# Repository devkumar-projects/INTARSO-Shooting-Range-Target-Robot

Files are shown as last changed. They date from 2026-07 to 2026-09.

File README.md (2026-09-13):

# INTARSO — Shooting-Range Target Robot Controller







A full electronics and control-system retrofit for **INTARSO**, a motorized target-retrieval robot used on a shooting range: the robot rides on a rail, carries a paper target out to a commanded distance (up to 24 m), presents it front/side/back on command, detects when it's been hit, and reports live telemetry to a wireless tablet interface — all built around an **ESP32**, a **VESC** motor controller, and a 2D **LiDAR** rangefinder.

This project was delivered by **AMJE Arts et Métiers Junior Études** in partnership with **JEECE** (a fellow Junior-Entreprise specialized in embedded electronics), to replace the robot's original, failing control electronics end-to-end.

<p align="center">
  <a href="https://youtube.com/shorts/YrYRk8fM58c">
    INTARSO on-site demonstration — watch on YouTube
  </a>
  <br>
  <em>▶️ <a href="https://youtube.com/shorts/YrYRk8fM58c">Watch the on-site demonstration on YouTube</a></em>
</p>

<p align="center">
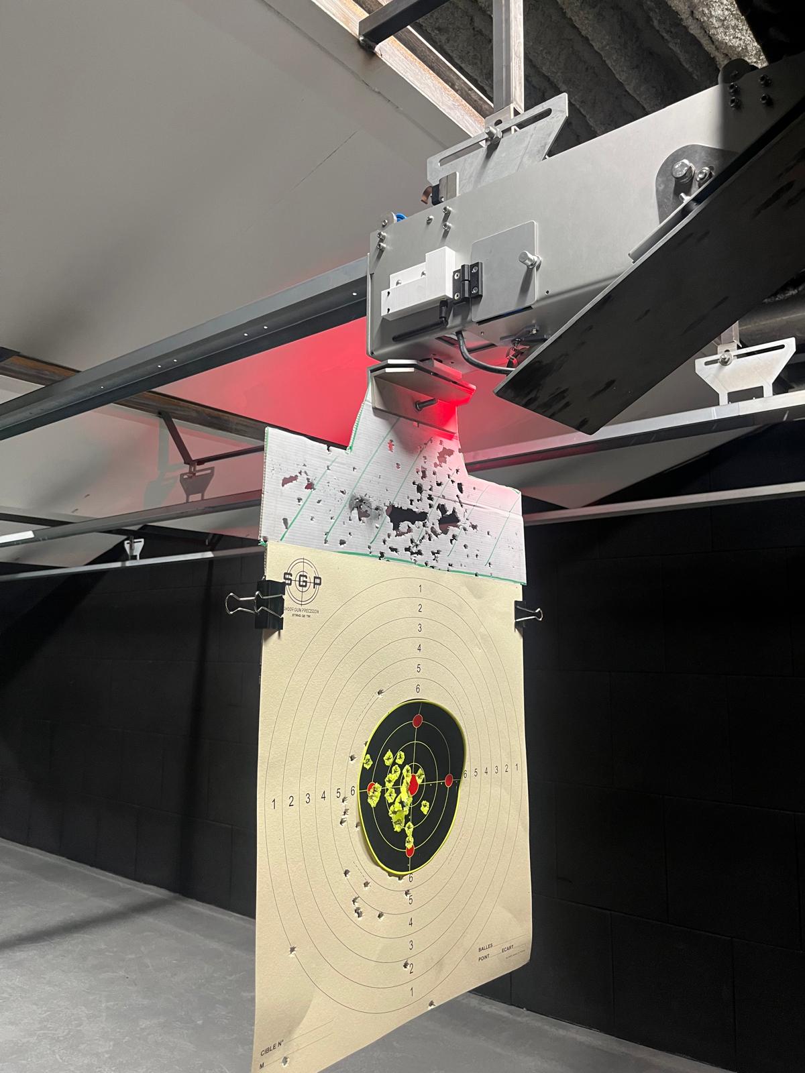
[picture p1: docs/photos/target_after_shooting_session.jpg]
INTARSO target after a live shooting session
  
  &nbsp;
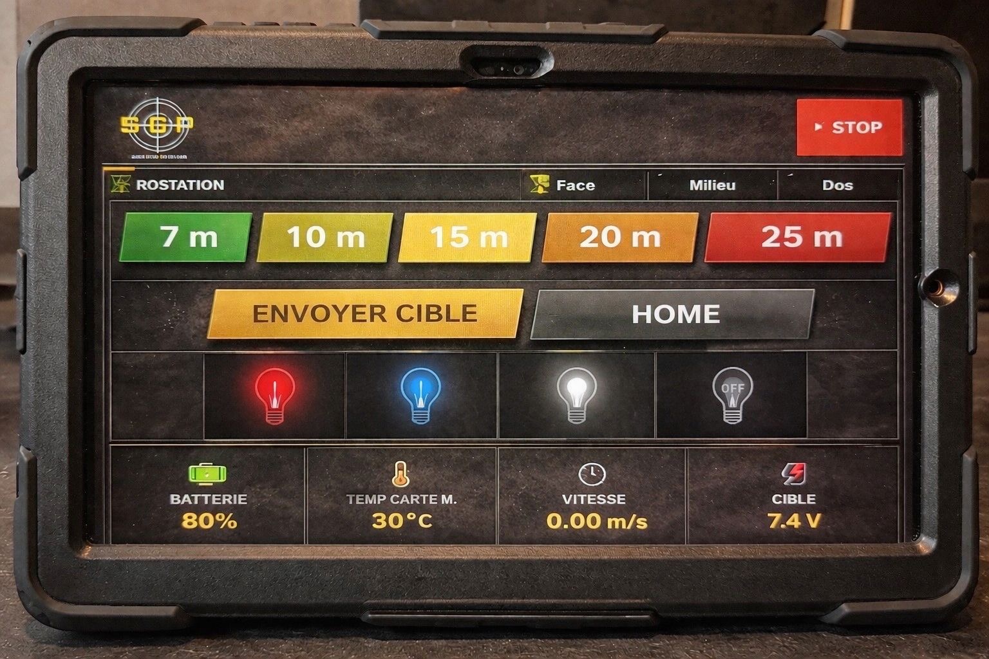
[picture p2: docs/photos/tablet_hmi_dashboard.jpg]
Wireless tablet HMI dashboard
  
</p>
<p align="center"><em>Left: the target board after a live session — the position-control loop reliably parked the robot at the commanded distances. Right: the wireless tablet dashboard (distance presets, live telemetry, target orientation, spot lighting).</em></p>

## Project outcome

The retrofit is **fully operational**: the robot accepts a target distance from the tablet (preset buttons or manual fine adjustment), drives there under closed-loop LiDAR feedback, holds position accurately enough for competitive shooting, detects impacts on the target via unexpected wheel motion while parked, and automatically returns home after an authenticated operator confirms the safety prompt. Every safety interlock described below (LiDAR signal loss, overcurrent/overheat, mechanical stall) was implemented and is active in the deployed firmware.

## System architecture

```mermaid
graph LR
    Tablet["Tablet / phone<br/>(any browser)"] <-->|WiFi AP<br/>HTTP + WebSocket| ESP32["ESP32<br/>main controller"]
    ESP32 <-->|UART 115200<br/>VescUart| VESC["VESC<br/>FOC motor controller"]
    ESP32 <-->|UART 921600| LiDAR["2D LiDAR<br/>rangefinder"]
    ESP32 -->|PWM| Servo["Servo motor<br/>target orientation"]
    ESP32 -->|P9813 protocol| LED["RGB spot LED<br/>status / hit indicator"]
    VESC -->|3-phase| Hub["Hub motor<br/>139 mm wheel"]
```

| Signal | ESP32 pin | Peripheral pin |
|---|---|---|
| VESC UART | GPIO 16 (RX) / 17 (TX) | TX / RX |
| VESC 5V | — | powers the LiDAR's 5V rail (shared, for a stable supply) |
| LiDAR UART | GPIO 14 (RX) / 27 (TX) | TX / RX |
| Servo PWM | GPIO 5 | signal (brown = GND, red = 5V) |
| P9813 LED driver | GPIO 19 (clock) / 23 (data) | CIN / DIN |

**Motor**: hub motor, 139 mm wheel, configured in the VESC as a large outrunner (2000 g profile), 20 poles (10 pole pairs), sensorless FOC, 150 W max power loss, driven directly (no gearbox — the wheel *is* the motor rotor).

## Control theory: position servo as state feedback with integral action

The firmware implements the position loop as a discrete PID on the LiDAR distance error. That PID is not an arbitrary heuristic — it's the direct discretization of a **state-feedback controller with integral action**, the same design pattern used in this author's other control-theory projects ([`RST-controller-for-an-inverted-pendulum`](https://github.com/devkumar-projects/RST-controller-for-an-inverted-pendulum), [`Control-of-an-instable-system-using-digital-state-feedback`](https://github.com/devkumar-projects/Control-of-an-instable-system-using-digital-state-feedback)). The derivation below documents the theoretical basis for the structure that was empirically tuned on the physical system.

**Plant model.** Treating the hub-motor-driven cart as a first-order velocity system (duty cycle → acceleration, with viscous/back-EMF damping):

<p align="center">
  <picture>
    <source media="(prefers-color-scheme: dark)" srcset="docs/equations/eq1_plant_dark.png">
    equation
  </picture>
</p>

where `x₁` is position (measured by the LiDAR), `x₂` is velocity, `u ∈ [−1, 1]` is the commanded duty cycle, `a` is the effective damping coefficient, and `b` is the motor gain.

**Integral augmentation.** To reject steady-state error (static friction, cable drag, slope of the rail), the tracking error is integrated as an extra state:

<p align="center">
  <picture>
    <source media="(prefers-color-scheme: dark)" srcset="docs/equations/eq2_integral_dark.png">
    equation
  </picture>
</p>

**Augmented state-space system**, `X = [x₁, x₂, x₃]ᵀ`:

<p align="center">
  <picture>
    <source media="(prefers-color-scheme: dark)" srcset="docs/equations/eq3_statespace_dark.png">
    equation
  </picture>
</p>

**Full-state feedback control law**:

<p align="center">
  <picture>
    <source media="(prefers-color-scheme: dark)" srcset="docs/equations/eq4_control_law_dark.png">
    equation
  </picture>
</p>

which is exactly a PID acting on the position error, with the derivative term taken on measured velocity (avoiding derivative kick on setpoint changes) rather than on the error itself. Substituting the control law back into the state equation gives the closed-loop system matrix `A_cl = A − BK`; the theoretical design method is to place the three closed-loop poles of `det(sI − A_cl) = 0` (e.g. via pole placement or an LQR cost) to hit a target settling time and damping ratio, which is what would determine `K_p`, `K_i`, `K_d` from `a` and `b` in a fully model-based design.

**What the firmware actually does** is the discrete-time version of this law, tuned empirically directly on the robot (since identifying `a` and `b` precisely for a friction-varying rail is impractical):

```cpp
float P = Kp * erreur;
integral = constrain(integral + erreur * dt, -1000, 1000);   // anti-windup clamp
float I = Ki * integral;
float D = Kd * (erreur - erreur_precedente);                  // discrete derivative
float target_duty = constrain(P + I + D, -dynamic_max_duty, dynamic_max_duty);
```

with a 20 ms control period (50 Hz), an **anti-windup clamp** on the integral term, a **slew-rate limiter** on the output duty cycle (`ACCEL_STEP`) to avoid current spikes through the VESC, and a **dynamically reduced maximum duty cycle** below 300 mm from the target for a soft, precise final approach.

**Wheel kinematics** — converting motor electrical RPM to linear speed and distance:

<p align="center">
  <picture>
    <source media="(prefers-color-scheme: dark)" srcset="docs/equations/eq5_wheel_rev_dark.png">
    equation
  </picture>
</p>

<p align="center">
  <picture>
    <source media="(prefers-color-scheme: dark)" srcset="docs/equations/eq6_speed_dark.png">
    equation
  </picture>
</p>

where `p = 10` is the number of pole pairs (20 poles), so mechanical RPM `= ERPM/p`.

## Firmware behavior (main control loop)

1. **Network + sensor processing** — handles incoming HTTP/WebSocket requests, then reads and low-pass filters (0.6/0.4 coefficient) the LiDAR frame.
2. **LiDAR signal-loss safety** — if no valid LiDAR frame arrives for 500 ms while moving, the robot brakes immediately and the spot LED turns red.
3. **Telemetry broadcast** — every 500 ms, battery voltage, motor current, MOSFET temperature, and speed are read from the VESC and pushed to every connected client as JSON over WebSocket.
4. **Movement branch** (state-feedback/PID, above) — runs at 50 Hz while a target distance is active; stops and actively brakes (5 A brake current) once the error is under 120 mm and duty is under 5%. Overcurrent (>20 A) or overheat (>75°C) triggers an immediate stop.
5. **Hit-detection branch** — while parked, the firmware polls the VESC's RPM every 20 ms; unexpected wheel rotation (>0.20 RPM), occurring at least 5 seconds after the last move and only when the robot isn't already home, is interpreted as an impact. It lights the LED red, raises a `hittarget` flag broadcast to the tablet (triggering a full-screen alert requiring an authenticated operator confirmation), and automatically drives the robot home once acknowledged.
6. **Stall safety** — if the measured distance hasn't moved by more than 10 mm in 2 seconds despite an active duty command above 10%, the robot is considered mechanically stuck and stops.

## Wireless HMI

The ESP32 serves a self-contained single-page web app (no external hosting needed) over its own WiFi access point, with live state pushed over WebSocket:

- distance presets (7/10/15/20/24 m) plus manual ±1 m fine adjustment
- target orientation control (front / middle / back) via the servo
- spot-light color control (blue / white / off / red-on-hit)
- live telemetry: voltage, battery %, MOSFET temperature, speed, measured position
- a full-screen hit alert that requires an authenticated operator confirmation before the robot resumes normal operation

## Security and provisioning

The firmware does not contain a production Wi-Fi password or operator code. Before compiling:

1. Copy `firmware/main_controller/secrets.example.h` to `firmware/main_controller/secrets.h`.
2. Set a unique Wi-Fi password (at least 8 characters) and a random API token (at least 32 characters).
3. Keep `secrets.h` local; it is ignored by Git and must never be committed.

All actuator endpoints require the API token through the `X-API-Key` header. The browser dashboard asks for the token locally and stores it only in that browser's local storage. The OTA update endpoint is intentionally disabled; update the ESP32 through a controlled, authenticated flashing workflow.

## Mechanical design

Custom enclosure and mounts designed for this retrofit, 3D-printed and integrated onto the existing rail chassis:

<p align="center">
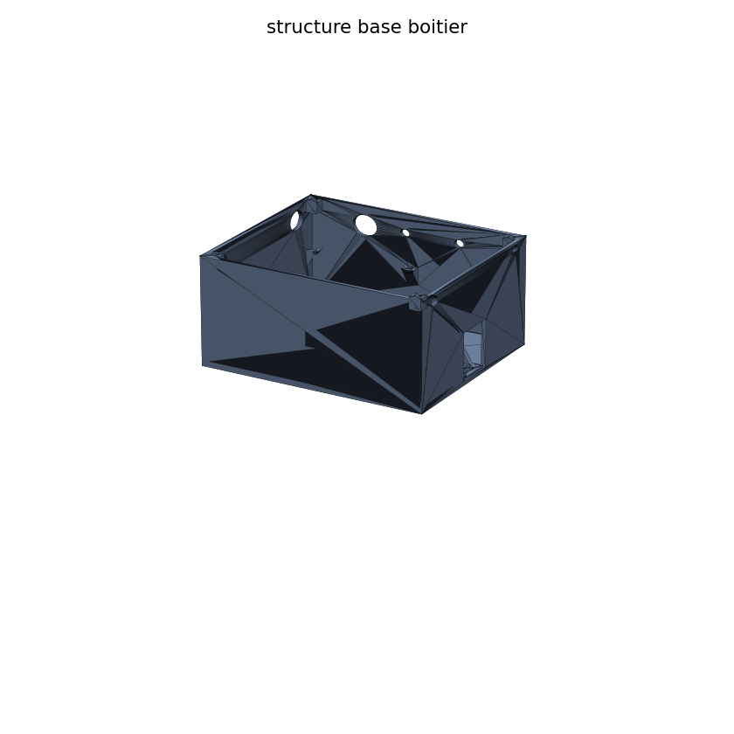
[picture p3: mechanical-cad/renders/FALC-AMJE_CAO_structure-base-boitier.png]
Enclosure base structure
  
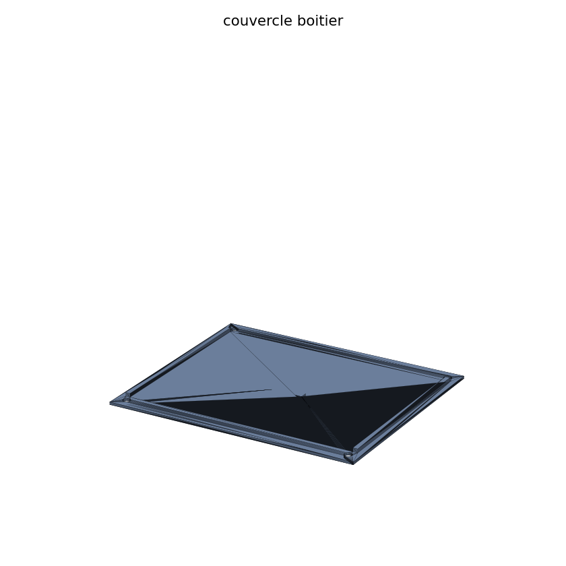
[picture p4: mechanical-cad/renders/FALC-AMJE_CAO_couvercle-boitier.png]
Enclosure lid
  
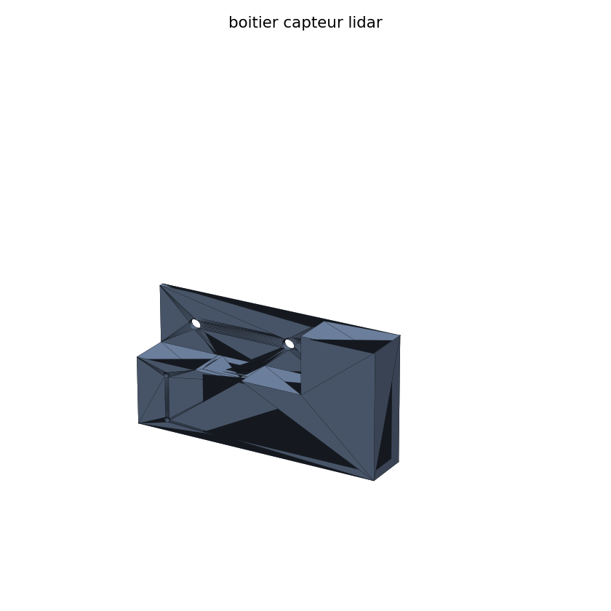
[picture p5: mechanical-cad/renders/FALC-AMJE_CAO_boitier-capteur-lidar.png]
LiDAR sensor housing
  
</p>
<p align="center">
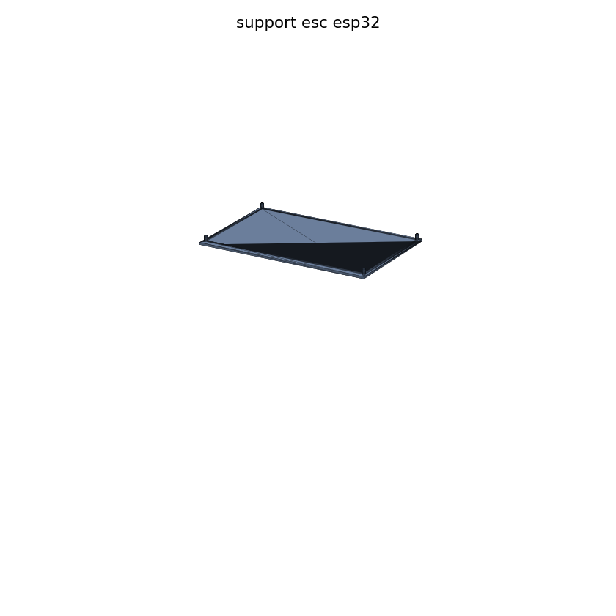
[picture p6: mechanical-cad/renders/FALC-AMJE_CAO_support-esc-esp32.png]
ESC/ESP32 mount
  
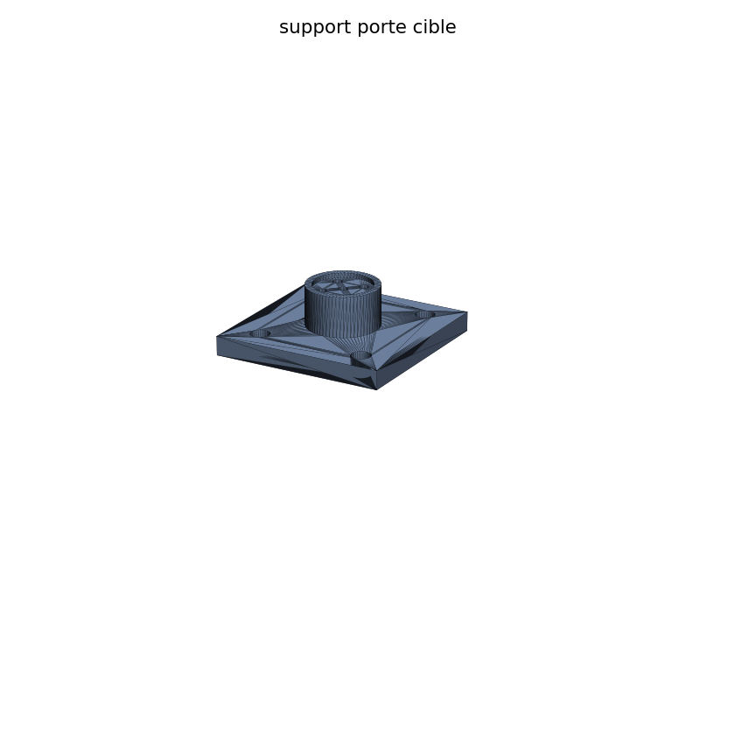
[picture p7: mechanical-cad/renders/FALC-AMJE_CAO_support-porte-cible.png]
Target-holder mount
  
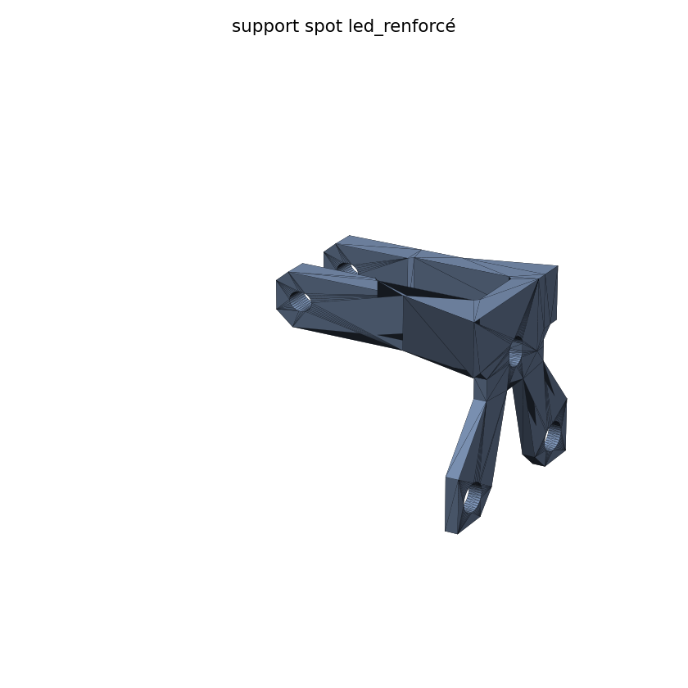
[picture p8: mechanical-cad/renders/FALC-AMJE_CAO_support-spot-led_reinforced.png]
Reinforced spotlight mount
  
</p>
<p align="center"><em>Renders generated directly from the STL files in this repository (matplotlib, shaded by face normals) — not marketing images.</em></p>

<p align="center">
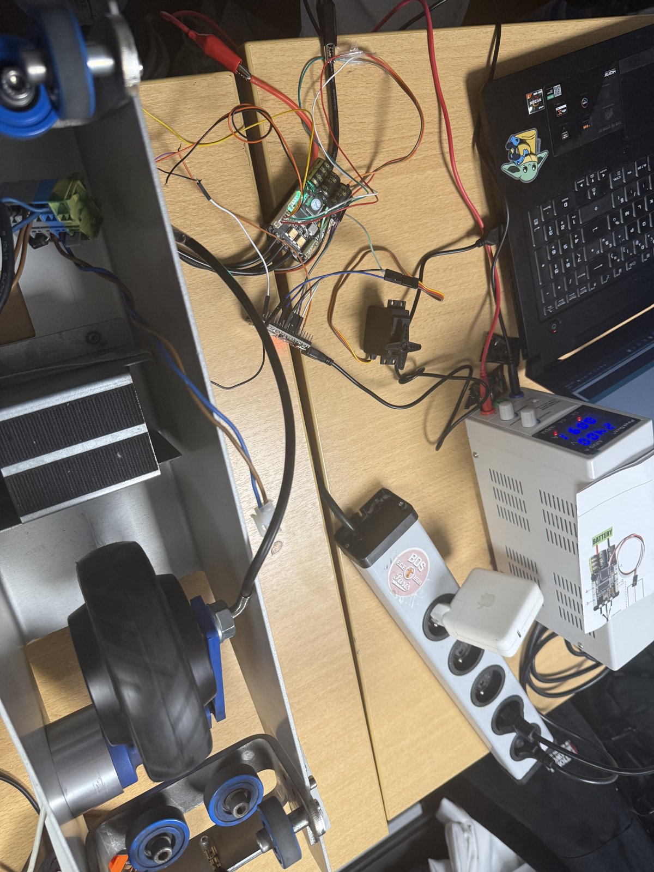
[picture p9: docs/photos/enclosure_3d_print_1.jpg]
3D-printed enclosure, printed part
  
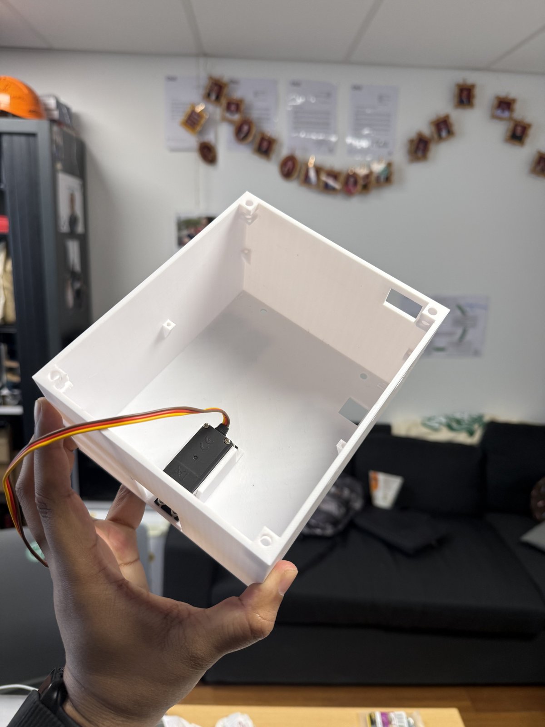
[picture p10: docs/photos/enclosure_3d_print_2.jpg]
3D-printed enclosure, second view
  
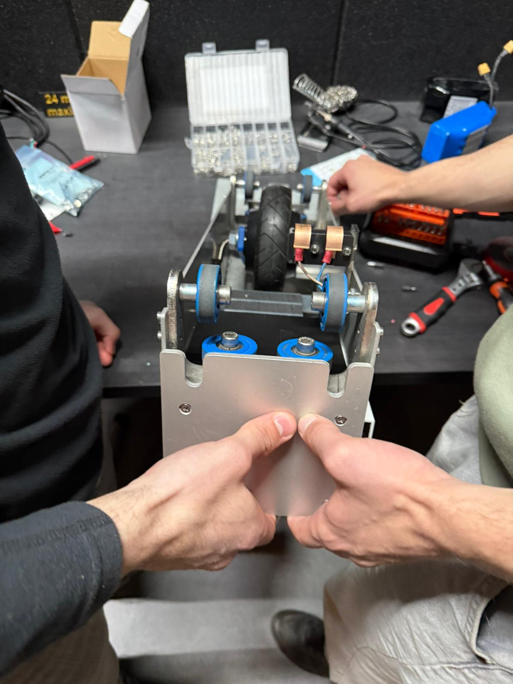
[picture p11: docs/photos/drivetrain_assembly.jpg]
Drivetrain and hub motor assembly
  
</p>
<p align="center"><em>The 3D-printed parts as manufactured, and the hub-motor drivetrain being assembled onto the rail carriage.</em></p>

Six parts were designed (STEP + STL provided in [`mechanical-cad/`](mechanical-cad)): the enclosure's base structure and lid, a dedicated LiDAR sensor housing, a mount for the ESC and ESP32, a mount for the target holder, and a reinforced mount for the spotlight (this last one needed reinforcing after the original print proved too fragile in testing — a reminder that first-iteration 3D-printed brackets rarely survive first contact with a shooting range).

## Electronics

- **Schematic**: designed in KiCad — [`electronics-kicad/projet_falc.kicad_sch`](electronics-kicad/projet_falc.kicad_sch)
- **PCB**: a KiCad PCB project file is included, but no copper layout was finalized for this phase — the schematic and point-to-point wiring table above are the actual deliverable used in the field.

<p align="center">
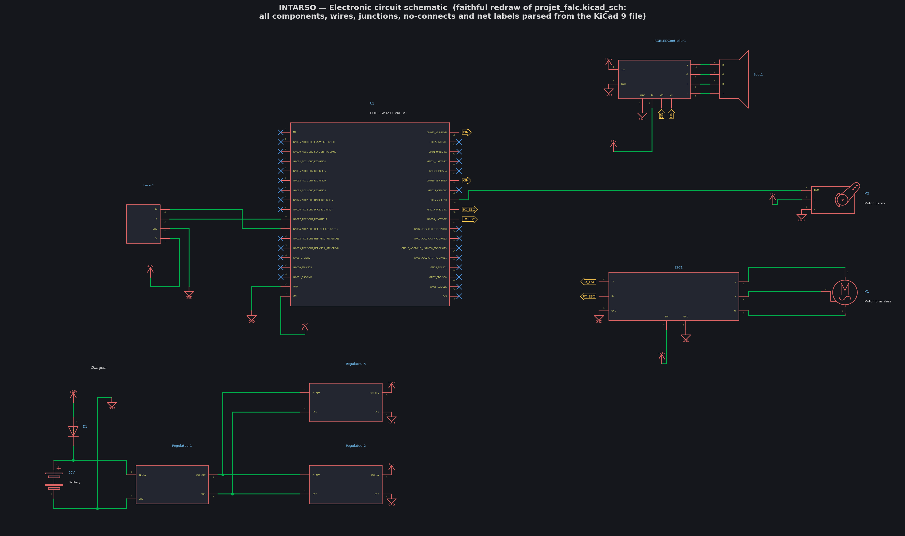
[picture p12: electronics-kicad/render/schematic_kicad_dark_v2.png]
Schematic reconstruction from the KiCad file
  
</p>
<p align="center"><em>Faithful redraw of <code>projet_falc.kicad_sch</code>: every symbol's real body graphics, pins, wires, junctions, no-connects and net labels (DIN/CIN, TX_ESC/RX_ESC) parsed straight from the KiCad 9 file — connectivity machine-verified (103/103 pins attached, 0 dangling wires). Visible blocks: ESP32 dev kit, VESC ESC + brushless hub motor, MOSFET module driving the RGB spot, servo, TOF/LiDAR rangefinder, and the 36V battery → 24V → 12V/5V regulator chain.</em></p>

## Repository layout

```
firmware/
├── main_controller/            Full ESP32 firmware: WiFi AP, HTTP+WebSocket server,
│                                state-feedback/PID position loop, hit detection,
│                                safety interlocks, embedded HTML/JS tablet UI
│   └── tablet_ui.html           Standalone copy of the dashboard UI (the served
│                                version is embedded as a PROGMEM string in the
│                                .ino; this file mirrors it for readability/editing)
└── tests_and_calibration/       Standalone unit tests used during bring-up
    ├── lidar_test/               Raw LiDAR frame parsing test
    ├── servo_sweep_test/         Basic servo sweep
    ├── servo_pulse_calibration/  Servo min/max pulse-width calibration
    ├── led_test/                 P9813 RGB spot LED test
    └── vesc_uart_test/           VESC UART link test (read telemetry + send duty)

electronics-kicad/               KiCad schematic, symbol library, project files
mechanical-cad/
├── step/                        Editable CAD (STEP) for all 6 printed parts
├── stl/                         Print-ready STL for all 6 printed parts
└── renders/                     Shaded preview renders generated from the STLs
docs/photos/                     Real photos: target after a session, tablet HMI,
                                  3D-printed parts, drivetrain assembly
```

## Skills demonstrated

- **Embedded systems**: ESP32 firmware architecture, multi-peripheral UART management (VESC + LiDAR sharing a single MCU), non-blocking main-loop design under a WiFi server and WebSocket broadcast
- **Control theory**: state-space modeling, integral-augmented state feedback, discrete PID implementation with anti-windup and slew-rate limiting, informed by pole-placement/LQR design principles
- **Motor control**: VESC FOC configuration for a sensorless hub motor (pole count, power limits, UART app mode), ERPM-to-linear-speed kinematics
- **Sensor integration**: UART LiDAR frame framing, range validation and low-pass filtering
- **Safety-critical design**: multiple independent interlocks (signal loss, overcurrent/overheat, mechanical stall, unexpected motion) that fail toward a safe stop
- **Full-stack embedded UI**: a complete HTML/CSS/JS single-page app served directly from ESP32 flash, communicating over HTTP + WebSocket with no external dependency
- **Electronics**: schematic capture in KiCad
- **Mechanical design**: parametric CAD for a custom enclosure and sensor/actuator mounts, iterated based on real-world failure (the reinforced spotlight mount)

## Note on excluded deliverables

The original project deliverables (a detailed PDF/DOCX report and wiring synoptic, written in French for the client) are not included in this repository — the content relevant to understanding and reproducing the system has been translated and restructured into this README instead.

## License

MIT — see [LICENSE](LICENSE).

---

*Authors — Dev Kumar & [Tedjeddine Sebiane](https://www.linkedin.com/in/tedjeddinesebiane), in collaboration with JEECE · AMJE Arts et Métiers Junior Études*

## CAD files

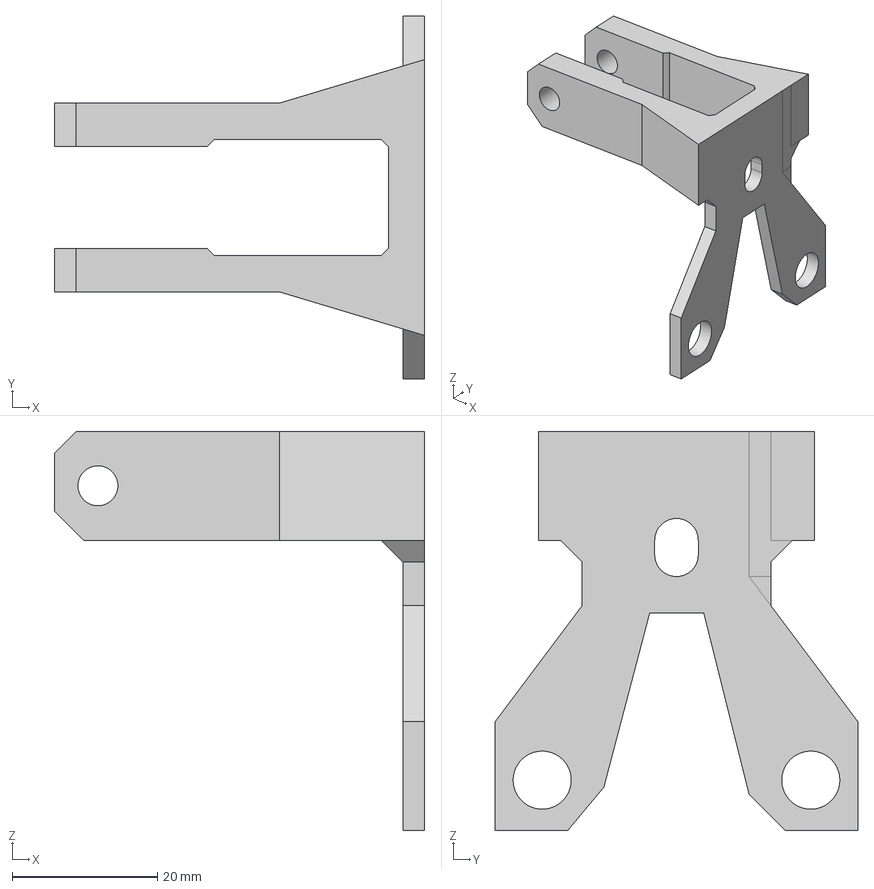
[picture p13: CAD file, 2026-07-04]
mechanical-cad/step/FALC-AMJE_CAO_support-spot-led_reinforced.step
51.0 x 50.0 x 55.0 mm

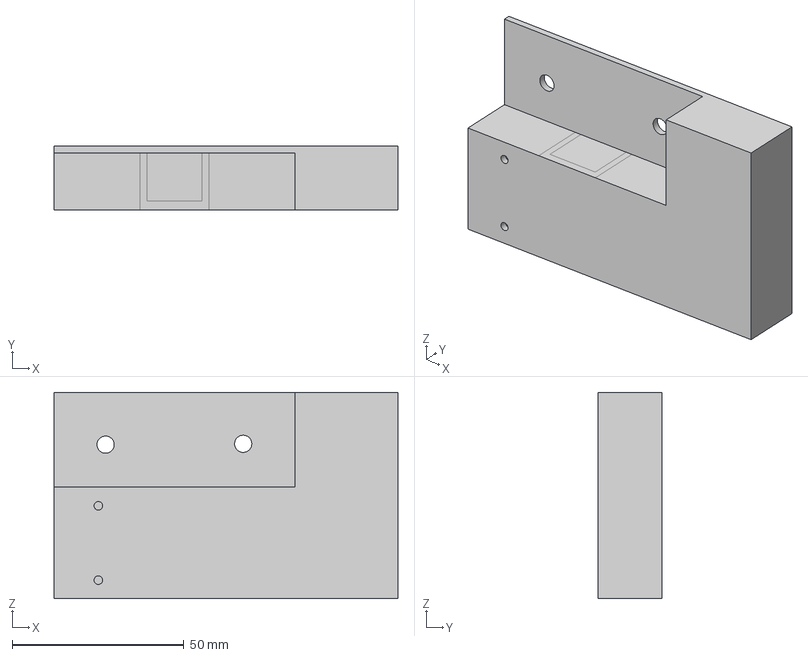
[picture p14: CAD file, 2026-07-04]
mechanical-cad/step/FALC-AMJE_CAO_boitier-capteur-lidar.step
100.0 x 18.5 x 60.0 mm

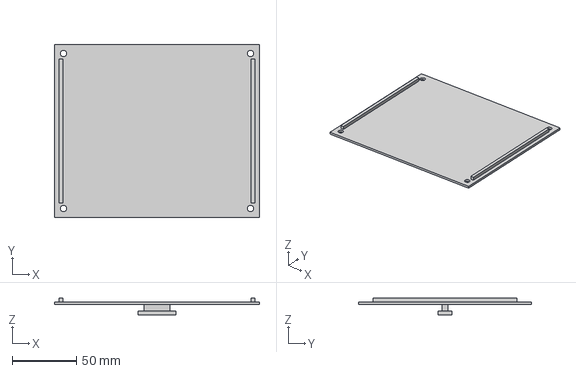
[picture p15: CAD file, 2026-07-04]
mechanical-cad/step/FALC-AMJE_CAO_couvercle-boitier.step
160.0 x 135.0 x 13.0 mm

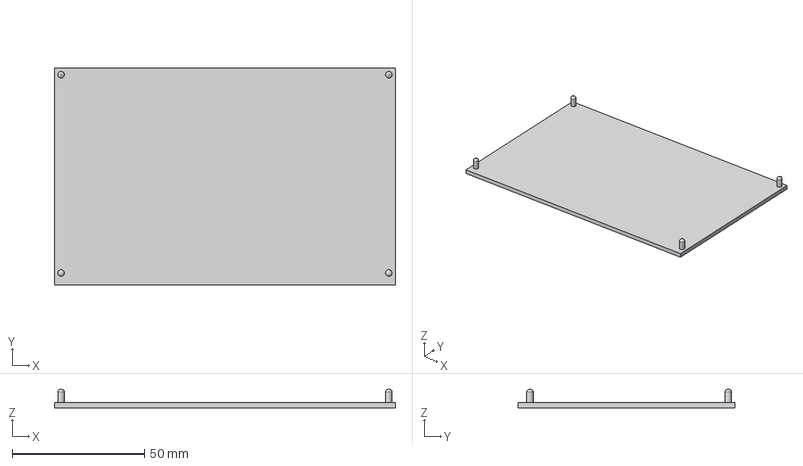
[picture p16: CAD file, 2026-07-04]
mechanical-cad/step/FALC-AMJE_CAO_support-esc-esp32.step
129.0 x 82.0 x 7.00 mm

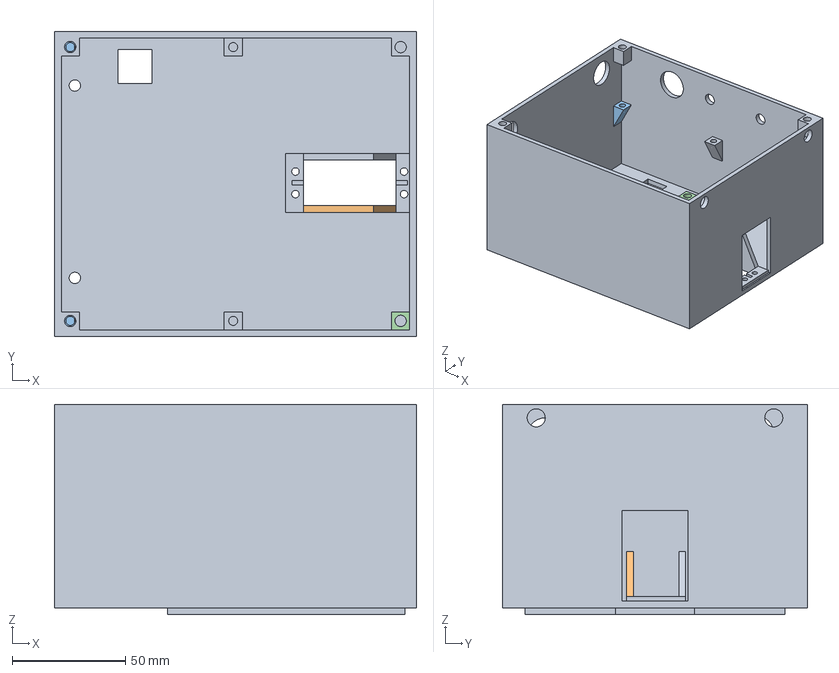
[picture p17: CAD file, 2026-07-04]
mechanical-cad/step/FALC-AMJE_CAO_structure-base-boitier.step
160.0 x 135.0 x 93.0 mm

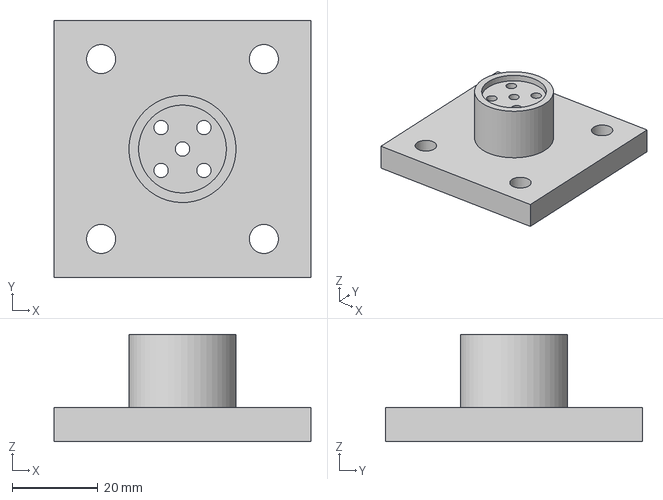
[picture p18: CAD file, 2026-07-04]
mechanical-cad/step/FALC-AMJE_CAO_support-porte-cible.step
60.0 x 60.0 x 25.0 mm

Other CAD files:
mechanical-cad/stl/FALC-AMJE_CAO_boitier-capteur-lidar.stl
mechanical-cad/stl/FALC-AMJE_CAO_couvercle-boitier.stl
mechanical-cad/stl/FALC-AMJE_CAO_structure-base-boitier.stl
mechanical-cad/stl/FALC-AMJE_CAO_support-esc-esp32.stl
mechanical-cad/stl/FALC-AMJE_CAO_support-porte-cible.stl
mechanical-cad/stl/FALC-AMJE_CAO_support-spot-led_reinforced.stl

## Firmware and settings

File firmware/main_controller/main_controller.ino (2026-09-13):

#include <WiFi.h>
#include <WebServer.h>
#include <WebSocketsServer.h>
#include <ESP32Servo.h>
#include <VescUart.h>
#include <HardwareSerial.h>
#include <ArduinoJson.h>
#include <FastLED.h>
#include <string.h>
#include "secrets.h"

// --- PIN CONFIGURATION ---
#define NUM_LEDS 1
#define DATA_PIN 23
#define CLOCK_PIN 19
#define PIN_ROT 5
#define DISTANCEMAX 24000 //distance max possible
#define DISTANCEMAXREEL 24830 //distance initial du robot. (distance lu par le lidar lorque le robot est au point 0)

HardwareSerial LidarSerial(1); 
HardwareSerial VescSerial(2);  
VescUart vesc;
Servo servoRot;
CRGB leds[NUM_LEDS];

// --- WIFI / AUTHENTICATION ---
// Keep the real values in secrets.h (ignored by Git), copied from
// secrets.example.h. Motion and actuator routes require X-API-Key.
const char* AP_SSID = INTARSO_AP_SSID;
const char* AP_PASS = INTARSO_AP_PASS;
const char* API_TOKEN = INTARSO_API_TOKEN;
WebServer server(80);
WebSocketsServer webSocket = WebSocketsServer(81);
const char* AUTH_HEADER_KEYS[] = {"X-API-Key", "Authorization"};

bool credentialsConfigured() {
  return AP_PASS != nullptr && strlen(AP_PASS) >= 8 &&
         strcmp(AP_PASS, "REPLACE_WITH_A_STRONG_AP_PASSWORD") != 0 &&
         API_TOKEN != nullptr && strlen(API_TOKEN) >= 32 &&
         strcmp(API_TOKEN, "REPLACE_WITH_A_RANDOM_API_TOKEN") != 0;
}

bool requireApiKey() {
  if (!credentialsConfigured()) {
    server.send(503, "text/plain", "Robot credentials are not configured");
    return false;
  }

  String provided = server.header("X-API-Key");
  if (!provided.length()) {
    String authorization = server.header("Authorization");
    if (authorization.startsWith("Bearer ")) {
      provided = authorization.substring(7);
    }
  }

  if (provided != String(API_TOKEN)) {
    server.send(401, "text/plain", "Authentication required");
    return false;
  }
  return true;
}

// --- STATE & TARGET ---
unsigned long lastLidarTime = 0;
const float initial_dist = DISTANCEMAXREEL;
float current_dist_mm = 0;
float filtered_dist_mm = 0;
float target_dist_mm = 0; 
int rot_pos = 5;                   // servo position in degrees
bool moving_translation = false;
float distance_par_tour = 0.4366;  //distance pour un tour de roue
float distanceRobot = 0;
int hitCible = 0;
static unsigned long lastPID = 0;


// --- PID PARAMETERS ---
float Kp = 0.00030; 
float Ki = 0.000010; 
float Kd = 0.00045;  
float erreur_precedente = 0;
float integral = 0;
const float MAX_DUTY = 0.30;  // max speed as duty cycle (percentage of voltage sent to the motor) do not exceed 0.66
// WARNING: if the speed is changed, the PID values will need to be re-tuned as well.

// --- RAMP PARAMETERS ---
float current_duty = 0;          
const float ACCEL_STEP = 0.005;

//interface:
const char index_html[] PROGMEM = R"rawliteral(
<!DOCTYPE html>
<html lang="en">
<head>
<meta charset="UTF-8">
<meta name="viewport" content="width=device-width, initial-scale=1.0, user-scalable=no">
<title>Robot Interface</title>
<style>
  :root {
    --bg:      #050505;
    --panel:   #0a0a0a;
    --gold:    #B79A4A;
    --gold-hi: #D4B86A;
    --gold-dk: #7A6430;
    --txt:     #F0E4CC;
    --gray:    #5A5A5A;
    --red:     #C0392B;
    --red-hi:  #E74C3C;
    --blue:    #1A6FA8;
    --blue-hi: #4AA8FF;
    --green:   #27AE60;
    --orange:  #E67E22;
    --border:  #1E1A10;
    --white-bulb: #F3F3F3;
  }

  * { box-sizing: border-box; margin: 0; padding: 0; }

  html, body {
    width: 100%;
    height: 100%;
    background: var(--bg);
    color: var(--txt);
    font-family: 'Arial Narrow', Arial, sans-serif;
    overflow: hidden;
    user-select: none;
    -webkit-user-select: none;
  }

  #app {
    display: grid;
    grid-template-rows: 125px auto 1fr 68px;
    height: 100vh;
    padding: 4px 10px 4px;
    gap: 6px;
  }

  /* ── TOPBAR ── */
  #topbar {
    display: flex;
    align-items: center;
    justify-content: space-between;
    gap: 10px;
    background: #000000;
    margin: -4px -10px 0;
    padding: 6px 14px 6px;
    border-bottom: 2px solid #000000;
  }

  #top-logo-wrap {
    display: flex;
    align-items: center;
    flex: 1;
    min-width: 0;
  }

  #top-logo {
    max-height: 115px;
    max-width: 100%;
    object-fit: contain;
    display: block;
  }

  #stop-btn {
    background: var(--red);
    color: white;
    font-family: 'Arial Narrow', Arial, sans-serif;
    font-size: 1.5rem;
    font-weight: 700;
    letter-spacing: 3px;
    border: none;
    padding: 0 26px;
    height: 62px;
    cursor: pointer;
    clip-path: polygon(8px 0%, 100% 0%, calc(100% - 8px) 100%, 0% 100%);
    transition: background .15s;
    flex-shrink: 0;
    box-shadow: 0 0 20px rgba(192,57,43,.45);
  }
  #stop-btn:active { background: var(--red-hi); }

  /* ── NIVEAU 1 : ACTIONS PRINCIPALES ── */
  #level1 {
    background: var(--panel);
    border: 1px solid var(--border);
    border-left: 3px solid var(--gold);
    padding: 8px 12px 10px;
    display: flex;
    flex-direction: column;
    gap: 8px;
  }

  .preset-row {
    display: flex;
    gap: 6px;
  }

  .preset-btn {
    background: #111;
    color: var(--gold);
    font-family: 'Arial Narrow', Arial, sans-serif;
    font-size: 1.5rem;
    font-weight: 700;
    border: 1.5px solid var(--gold-dk);
    height: 56px;
    flex: 1;
    cursor: pointer;
    letter-spacing: 1px;
    transition: background .12s, color .12s, border-color .12s;
    clip-path: polygon(5px 0%, 100% 0%, calc(100% - 5px) 100%, 0% 100%);
  }
  .preset-btn:active { background: var(--gold); color: #111; border-color: var(--gold-hi); }

  .target-row {
    display: flex;
    align-items: center;
    gap: 8px;
    justify-content: center;
  }

  .adj-btn {
    background: var(--gold-dk);
    color: var(--txt);
    font-family: 'Arial Narrow', Arial, sans-serif;
    font-size: 1.8rem;
    font-weight: 700;
    border: none;
    width: 46px;
    height: 46px;
    cursor: pointer;
    clip-path: polygon(6px 0%, 100% 0%, calc(100% - 6px) 100%, 0% 100%);
    transition: background .12s;
    display: flex;
    align-items: center;
    justify-content: center;
    flex-shrink: 0;
  }
  .adj-btn:active { background: var(--gold); color: #111; }

  #target-display {
    background: var(--gold);
    color: #111;
    font-family: 'Courier New', Courier, monospace;
    font-size: 1.65rem;
    font-weight: 700;
    flex: 1;
    max-width: 180px;
    height: 46px;
    display: flex;
    align-items: center;
    justify-content: center;
    clip-path: polygon(6px 0%, 100% 0%, calc(100% - 6px) 100%, 0% 100%);
  }

  .action-row {
    display: flex;
    gap: 10px;
  }

  .send-btn {
    background: linear-gradient(135deg, var(--gold-dk), var(--gold));
    color: #111;
    font-family: 'Arial Narrow', Arial, sans-serif;
    font-size: 1.45rem;
    font-weight: 700;
    letter-spacing: 2px;
    border: none;
    height: 64px;
    flex: 3;
    cursor: pointer;
    clip-path: polygon(8px 0%, 100% 0%, calc(100% - 8px) 100%, 0% 100%);
    transition: filter .15s;
    box-shadow: 0 0 18px rgba(183,154,74,.35);
  }
  .send-btn:active { filter: brightness(1.3); }

  .home-btn {
    background: linear-gradient(135deg, var(--blue), var(--blue-hi));
    color: #fff;
    font-family: 'Arial Narrow', Arial, sans-serif;
    font-size: 1.45rem;
    font-weight: 700;
    letter-spacing: 2px;
    border: none;
    height: 64px;
    flex: 2;
    cursor: pointer;
    clip-path: polygon(8px 0%, 100% 0%, calc(100% - 8px) 100%, 0% 100%);
    transition: filter .15s;
    box-shadow: 0 0 18px rgba(26,111,168,.35);
  }
  .home-btn:active { filter: brightness(1.3); }

  /* ── NIVEAU 2 : SECONDAIRE (remplit l'espace restant) ── */
  #level2 {
    display: grid;
    grid-template-columns: 1fr 1fr;
    gap: 6px;
    min-height: 0;
  }

  .panel {
    background: var(--panel);
    border: 1px solid var(--border);
    padding: 7px 10px 8px;
    display: flex;
    flex-direction: column;
    gap: 5px;
    position: relative;
    min-height: 0;
  }
  .panel::before {
    content: '';
    position: absolute;
    top: 0; left: 0;
    width: 28px; height: 2px;
    background: var(--gold);
  }

  .panel-title {
    font-size: .78rem;
    font-weight: 700;
    color: var(--gold);
    letter-spacing: 3px;
    text-transform: uppercase;
    flex-shrink: 0;
  }

  .sensor-row {
    display: flex;
    align-items: center;
    justify-content: space-between;
    background: #0f0f0f;
    border: 1px solid var(--border);
    padding: 3px 8px;
    flex-shrink: 0;
  }

  .sensor-label {
    font-size: .66rem;
    color: var(--gray);
    letter-spacing: 2px;
  }

  .sensor-value {
    font-family: 'Courier New', Courier, monospace;
    font-size: 1rem;
    color: var(--gold-hi);
  }
  .sensor-value.moving { color: var(--green); }

  /* -- ROTATION GRID -- fills the vertical space -- */
  .rot-grid {
    display: grid;
    grid-template-columns: 1fr 1fr 1fr;
    gap: 5px;
    flex: 1;
  }

  .rot-btn {
    background: #111;
    color: var(--gold);
    font-family: 'Arial Narrow', Arial, sans-serif;
    font-size: 1.05rem;
    font-weight: 700;
    letter-spacing: 1px;
    border: 1px solid var(--gold-dk);
    cursor: pointer;
    clip-path: polygon(5px 0%, 100% 0%, calc(100% - 5px) 100%, 0% 100%);
    transition: background .12s, color .12s, box-shadow .12s;
    width: 100%;
    height: 100%;
    padding: 6px 2px;
  }
  .rot-btn:active { background: var(--gold); color: #111; }
  .rot-btn.active {
    background: var(--gold);
    color: #111;
    border-color: var(--gold-hi);
    box-shadow: 0 0 0 2px var(--gold-hi), 0 0 14px rgba(212,184,106,.5);
    font-weight: 900;
  }

  /* -- LIGHTING: large bulbs + OFF underneath -- */
  #panel-lights {
    display: flex;
    flex-direction: column;
    gap: 5px;
  }

  /* Colored bulbs area -- flex:1 to fill space */
  .bulbs-row {
    display: grid;
    grid-template-columns: 1fr 1fr 1fr;
    gap: 6px;
    flex: 1;
    min-height: 0;
  }

  .light-btn {
    background: #0d0d0d;
    border: 1.5px solid #2a2a2a;
    cursor: pointer;
    display: flex;
    flex-direction: column;
    justify-content: center;
    align-items: center;
    gap: 4px;
    padding: 8px 4px 6px;
    transition: transform .12s, border-color .15s, background .15s;
    clip-path: polygon(5px 0%, 100% 0%, calc(100% - 5px) 100%, 0% 100%);
    width: 100%;
    height: 100%;
  }
  .light-btn:active { transform: scale(0.95); }

  /* Bordure active */
  .light-btn.active[data-color="blue"]  { border-color: var(--blue-hi);  background: #071420; }
  .light-btn.active[data-color="white"] { border-color: #ccc;             background: #141414; }
  .light-btn.active[data-color="red"]   { border-color: var(--red-hi);   background: #1a0808; }

  /* ── SVG AMPOULE ── */
  .bulb-svg {
    width: 42px;
    height: 68px;
    flex-shrink: 0;
    transition: filter .2s;
    overflow: visible;
  }

  /* Globe — inactif */
  .bulb-svg .glass {
    fill: #1a1a1a;
    stroke: #383838;
    stroke-width: 1.5;
    transition: fill .2s, stroke .2s;
  }
  /* Reflet interne */
  .bulb-svg .shine {
    fill: rgba(255,255,255,.04);
    transition: fill .2s;
  }
  /* Filament */
  .bulb-svg .filament {
    stroke: #4a4a4a;
    stroke-width: 1.4;
    fill: none;
    stroke-linecap: round;
    stroke-linejoin: round;
    transition: stroke .2s;
  }
  /* Fils de support */
  .bulb-svg .wire {
    stroke: #363636;
    stroke-width: 1;
    transition: stroke .2s;
  }
  /* Metal base -- bands */
  .bulb-svg .base-a { fill: #525252; }
  .bulb-svg .base-b { fill: #363636; }
  .bulb-svg .contact { fill: #606060; }

  /* Tinte inactive selon couleur */
  .light-btn[data-color="blue"]  .bulb-svg .glass { fill: #0a1a28; stroke: #1a3e58; }
  .light-btn[data-color="white"] .bulb-svg .glass { fill: #1a1a1a; stroke: #444; }
  .light-btn[data-color="red"]   .bulb-svg .glass { fill: #220808; stroke: #5a1a1a; }

  /* ── ACTIF : couleur vive + halo ── */
  .light-btn.active[data-color="blue"] .bulb-svg {
    filter: drop-shadow(0 0 8px rgba(74,168,255,.9)) drop-shadow(0 0 18px rgba(74,168,255,.5));
  }
  .light-btn.active[data-color="blue"] .bulb-svg .glass   { fill: #4AA8FF; stroke: #b8ddff; }
  .light-btn.active[data-color="blue"] .bulb-svg .shine   { fill: rgba(255,255,255,.22); }
  .light-btn.active[data-color="blue"] .bulb-svg .filament { stroke: #fff; }
  .light-btn.active[data-color="blue"] .bulb-svg .wire    { stroke: #c0e0ff; }

  .light-btn.active[data-color="white"] .bulb-svg {
    filter: drop-shadow(0 0 8px rgba(255,255,255,.9)) drop-shadow(0 0 18px rgba(255,255,255,.45));
  }
  .light-btn.active[data-color="white"] .bulb-svg .glass   { fill: #F3F3F3; stroke: #ffffff; }
  .light-btn.active[data-color="white"] .bulb-svg .shine   { fill: rgba(255,255,255,.35); }
  .light-btn.active[data-color="white"] .bulb-svg .filament { stroke: #aaa; }
  .light-btn.active[data-color="white"] .bulb-svg .wire    { stroke: #ccc; }

  .light-btn.active[data-color="red"] .bulb-svg {
    filter: drop-shadow(0 0 8px rgba(231,76,60,.9)) drop-shadow(0 0 18px rgba(231,76,60,.5));
  }
  .light-btn.active[data-color="red"] .bulb-svg .glass   { fill: #E74C3C; stroke: #ff9090; }
  .light-btn.active[data-color="red"] .bulb-svg .shine   { fill: rgba(255,200,180,.22); }
  .light-btn.active[data-color="red"] .bulb-svg .filament { stroke: #ffddcc; }
  .light-btn.active[data-color="red"] .bulb-svg .wire    { stroke: #ff9090; }

  /* Label under the bulb */
  .bulb-label {
    font-family: 'Arial Narrow', Arial, sans-serif;
    font-size: .72rem;
    font-weight: 700;
    letter-spacing: 2px;
    text-transform: uppercase;
    color: var(--gray);
    transition: color .15s;
  }
  .light-btn[data-color="blue"]  .bulb-label { color: #245b80; }
  .light-btn[data-color="white"] .bulb-label { color: #555; }
  .light-btn[data-color="red"]   .bulb-label { color: #7a2d2d; }
  .light-btn.active[data-color="blue"]  .bulb-label { color: var(--blue-hi); }
  .light-btn.active[data-color="white"] .bulb-label { color: #ddd; }
  .light-btn.active[data-color="red"]   .bulb-label { color: var(--red-hi); }

  /* Bouton OFF — pleine largeur */
  .off-btn {
    width: 100%;
    height: 36px;
    border-radius: 4px;
    border: 1.5px solid #333;
    background: #111;
    color: #555;
    font-family: 'Arial Narrow', Arial, sans-serif;
    font-size: 1.1rem;
    font-weight: 700;
    letter-spacing: 3px;
    display: flex;
    justify-content: center;
    align-items: center;
    gap: 8px;
    cursor: pointer;
    transition: background .12s, color .12s, box-shadow .12s;
    clip-path: polygon(6px 0%, 100% 0%, calc(100% - 6px) 100%, 0% 100%);
    flex-shrink: 0;
  }
  .off-btn:active, .off-btn.active {
    background: #1e1e1e;
    color: #ccc;
    border-color: #666;
    box-shadow: 0 0 10px rgba(255,255,255,.1);
  }

  /* -- TELEMETRY -- */
  #telemetry {
    background: var(--panel);
    border: 1px solid var(--border);
    padding: 3px 8px 3px;
    display: grid;
    grid-template-rows: 14px 1fr;
    gap: 2px;
  }

  #tele-ws {
    display: flex;
    align-items: center;
    gap: 14px;
    border-bottom: 1px solid var(--border);
    padding-bottom: 2px;
    font-family: 'Courier New', Courier, monospace;
    font-size: .62rem;
    letter-spacing: 1px;
    color: var(--gray);
  }

  #ws-dot {
    width: 6px; height: 6px;
    border-radius: 50%;
    background: var(--red);
    display: inline-block;
    margin-right: 4px;
    animation: pulse-red 1.5s infinite;
  }
  #ws-dot.ok { background: var(--green); animation: pulse-green 2s infinite; }

  @keyframes pulse-red {
    0%,100% { box-shadow: 0 0 0 0 rgba(192,57,43,0); }
    50%     { box-shadow: 0 0 0 3px rgba(192,57,43,.5); }
  }
  @keyframes pulse-green {
    0%,100% { box-shadow: 0 0 0 0 rgba(39,174,96,0); }
    50%     { box-shadow: 0 0 0 3px rgba(39,174,96,.4); }
  }

  #tele-cells {
    display: grid;
    grid-template-columns: repeat(5, 1fr);
    gap: 3px;
  }

  .tele-cell {
    display: flex;
    flex-direction: column;
    align-items: center;
    justify-content: center;
    background: #0f0f0f;
    border: 1px solid var(--border);
    padding: 1px 2px;
  }

  .tele-icon  { font-size: .8rem; line-height: 1; }
  .tele-label { font-size: .58rem; color: var(--gray); letter-spacing: 1px; text-transform: uppercase; }
  .tele-value { font-family: 'Courier New', Courier, monospace; font-size: .88rem; color: var(--gold-hi); font-weight: 700; }
  .tele-value.warn  { color: var(--orange); }
  .tele-value.alert { color: var(--red-hi); }

  /* ── FLASH ── */
  .flash {
    position: fixed;
    bottom: 40px; left: 50%;
    transform: translateX(-50%);
    background: var(--gold);
    color: #111;
    font-family: 'Arial Narrow', Arial, sans-serif;
    font-weight: 700;
    font-size: .9rem;
    letter-spacing: 2px;
    padding: 5px 18px;
    opacity: 0;
    pointer-events: none;
    transition: opacity .2s;
    z-index: 999;
  }
  .flash.show { opacity: 1; }

  /* -- HIT ALERT MODAL -- */
  #hit-overlay {
    display: none;
    position: fixed;
    inset: 0;
    background: rgba(0,0,0,.82);
    z-index: 9999;
    justify-content: center;
    align-items: center;
    backdrop-filter: blur(3px);
  }
  #hit-overlay.show { display: flex; }

  #hit-box {
    background: #0e0e0e;
    border: 2px solid var(--red);
    box-shadow: 0 0 40px rgba(192,57,43,.6), 0 0 80px rgba(192,57,43,.25);
    padding: 28px 32px 24px;
    max-width: 88vw;
    display: flex;
    flex-direction: column;
    align-items: center;
    gap: 18px;
    clip-path: polygon(12px 0%, 100% 0%, calc(100% - 12px) 100%, 0% 100%);
    animation: hit-in .25s ease-out;
  }
  @keyframes hit-in { from { transform: scale(.88); opacity: 0; } to { transform: scale(1); opacity: 1; } }

  #hit-icon { font-size: 3.2rem; line-height: 1; animation: hit-pulse 1s infinite; }
  @keyframes hit-pulse {
    0%,100% { text-shadow: 0 0 0px rgba(231,76,60,0); }
    50%     { text-shadow: 0 0 20px rgba(231,76,60,.9); }
  }

  #hit-title { font-family: 'Arial Narrow', Arial, sans-serif; font-size: 1.25rem; font-weight: 700; letter-spacing: 3px; color: var(--red-hi); text-transform: uppercase; text-align: center; }
  #hit-msg   { font-family: 'Arial Narrow', Arial, sans-serif; font-size: 1.05rem; color: var(--txt); text-align: center; line-height: 1.6; letter-spacing: 1px; }
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
void loop() {
  server.handleClient();
  webSocket.loop();
  updateLidar();
  ////////////////////// lidar signal loss safety //////////////
  if (moving_translation && (millis() - lastLidarTime > 500)) {
    Serial.println("!!! ALERT: LIDAR SIGNAL LOST - EMERGENCY STOP !!!");
    leds[0] = CRGB::Red; 
    FastLED.show();
    stopRobot(); 
  }
  ////////////envoie data//////////
  static unsigned long lastMonitor = 0;
  if (millis() - lastMonitor > 500) {
    broadcastState();
    lastMonitor = millis();
  }


  if (moving_translation) { // robot movement function
    float erreur = filtered_dist_mm - target_dist_mm;
    if (abs(erreur) < 120 && abs(current_duty) < 0.05) {
      stopRobot();
    } 
    else {
      
      if (millis() - lastPID > 20) {////////////calcul pid///////////////
        float P = Kp * erreur;
        integral = constrain(integral + erreur*0.02, -1000, 1000);
        float I = Ki * integral;
        float D = Kd * (erreur - erreur_precedente);
        erreur_precedente = erreur;
        float dynamic_max_duty = (filtered_dist_mm < 300) ? 0.15 : MAX_DUTY;
        float target_duty = constrain(P + I + D, -dynamic_max_duty, dynamic_max_duty);
        if (current_duty < target_duty) {
          current_duty += ACCEL_STEP;
          if (current_duty > target_duty) current_duty = target_duty;
        } 
        else if (current_duty > target_duty) {
          current_duty -= ACCEL_STEP;
          if (current_duty < target_duty) current_duty = target_duty;
        }
        vesc.setDuty(-current_duty);
        lastPID = millis();
      }
      ///////////////////// overheat or overcurrent safety ///////////////
      if (abs(vesc.data.avgMotorCurrent) > 20.0 || vesc.data.tempMosfet > 75.0) { 
        Serial.println("!!! ALERT: OVERHEAT OR OVERCURRENT - STOP !!!");
        stopRobot();
      }
    }
  }
  ////////////si pas de mouvement alors detection de tir sur le robot/////////
  else { 
    static unsigned long lastBrakeCurrent = 0;
     if (millis() - lastBrakeCurrent > 20) { //la detection se fait toute les 20ms 
      //vesc.setBrakeCurrent(3.0);            // possible to add active braking here. (adding a brake reduces hit-detection sensitivity)
      vesc.getVescValues();

      if (abs(vesc.data.rpm) > 0.20 && (millis() - lastPID) > 5000 && target_dist_mm > 0 ){  // detection threshold 0.20 RPM value (increasing this value reduces sensitivity); detection starts 5s after the end of a move, and only if the robot isn't at the home position
        leds[0] = CRGB::Red; 
        FastLED.show();
        hitCible = 1;
        moving_translation = true;
        erreur_precedente = 0;
        integral = 0;
        current_duty = 0;
      }
      lastBrakeCurrent = millis();
      
    }
   
    
  }
  //////////////////////// safety: distance not changing despite motor command ///////////
  static float last_check_dist = 0;
  static unsigned long last_dist_change_time = 0;
  if (moving_translation && abs(current_duty) > 0.1) {
    if (abs(filtered_dist_mm - last_check_dist) > 10) { 
        last_check_dist = filtered_dist_mm;
        last_dist_change_time = millis();
    }
    if (millis() - last_dist_change_time > 2000) { // if the robot hasn't detected any lidar movement for 2s, it stops
        Serial.println("!!! ALERT: ROBOT STUCK OR LIDAR FROZEN !!!");
        stopRobot();
    }
  }
  else {
    last_dist_change_time = millis();
    last_check_dist = filtered_dist_mm;
  }
}

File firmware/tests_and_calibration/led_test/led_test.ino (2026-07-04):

#include <FastLED.h>


#define NUM_LEDS 1
#define DATA_PIN 23  
#define CLOCK_PIN 19 

CRGB leds[NUM_LEDS];

void setup() {
  Serial.begin(115200);
  Serial.println("--- P9813 LED UNIT TEST START ---");
 
  FastLED.addLeds<P9813, DATA_PIN, CLOCK_PIN, RGB>(leds, NUM_LEDS);
 
  FastLED.clear();
  FastLED.show();
  delay(1000);
}

void loop() {
 
  Serial.println("Red...");
  leds[0] = CRGB::Red;
  FastLED.show();
  delay(1000);

 
  Serial.println("Green...");
  leds[0] = CRGB::Green;
  FastLED.show();
  delay(1000);

 
  Serial.println("Blue...");
  leds[0] = CRGB::Blue;
  FastLED.show();
  delay(1000);

  
  Serial.println("White (full power)...");
  leds[0] = CRGB::White;
  FastLED.show();
  delay(1000);

  
  Serial.println("Off...");
  leds[0] = CRGB::Black;
  FastLED.show();
  delay(2000);
}

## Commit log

2026-07-04 Initial import: INTARSO target robot controller (ESP32/VESC/LiDAR firmware, KiCad schematic, mechanical CAD, docs)
    [FALC-AMJE_CAO_boitier-capteur-lidar.step, FALC-AMJE_CAO_boitier-capteur-lidar.stl, FALC-AMJE_CAO_couvercle-boitier.step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]
2026-07-04 docs: add schematic visual reconstructed from the KiCad file
2026-07-04 docs: improve schematic reconstruction (real pin/rect geometry), add on-site demo video
2026-07-04 fix: correct coordinate-transform bug for symbols without a body rectangle (motors, battery, spot RGB)
2026-07-04 docs: full KiCad-style dark schematic render (all symbol graphics, pins, junctions, no-connects, net labels; connectivity machine-verified)
2026-07-05 fix: rename schematic image to bust GitHub's stale CDN cache (enlarged view served an old version)
2026-07-05 docs: replace LaTeX math with pre-rendered PNG equations (light/dark variants) — GitHub mobile app does not render $$ math
2026-07-05 Add standalone tablet_ui.html mirroring the embedded ESP32 dashboard
2026-09-13 Fix embedded INTARSO hit alert after auth update
    [main_controller.ino]
